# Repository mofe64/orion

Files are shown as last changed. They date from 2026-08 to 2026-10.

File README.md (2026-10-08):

# Orion

Orion is an expressive robotic lamp. Its Raspberry Pi runs the hardware runtime,
local speech recognition and synthesis, and the Codex agent coordinator. Studio
provides scene authoring, robot controls, and voice settings. Speech works with
Studio closed; Codex inference and web search still require the internet.

## Start here

1. [Quickstart](docs/quickstart.md): set up a Pi, connect Studio and deploy updates.
2. [System architecture](docs/system-architecture.md): the processes on the Pi and how they talk.
3. [How Orion moves](docs/motion-architecture.md): from a request to servo movement.
4. [Voice architecture](docs/voice-architecture.md): wake word, transcription, agent and reply.
5. [Hardware versions](docs/hardware-versions.md): V1 and V2 lamps, V2 calibration and centring.

Everything else is in the [documentation index](docs/README.md).

## How a conversation flows

```text
microphone ─▶ wake word ─▶ record command ─▶ transcribe ─▶ Codex agent
                (Rustpotter)  (Silero)         (Qwen)          │
speaker + movement ◀─ oriond ◀─ gateway ◀─ synthesize reply ◀──┘
                                             (Piper)
```

Everything above runs on the Pi. Only Codex inference and web search go to the
internet. `oriond` plays the reply, animates the lamp to match the speech, and
owns the servos and the RGBW light. Studio connects to the Pi's authenticated
gateway for authoring, controls and settings; closing Studio does not stop the
lamp.

## Repository map

| Path | Responsibility |
| --- | --- |
| `agent/` | Rust conversation runtime, memory/tools, and Codex integration |
| `orion-service/` | Pi voice/agent host and Studio remote client |
| `runtime/` | Rust `oriond` daemon, hardware and MuJoCo backends, lifecycle, scenes, lighting, and playback |
| `coordinator/` | Reusable Rust voice orchestration, Pi transport, buffering, and playback lifecycle |
| `speech/` | CPU Qwen and Piper workers plus optional Apple Silicon development adapters |
| `orion_studio/` | Tauri/React desktop application and Pi gateway |
| `motion/` | Pose and motion assets plus Python consumers of Rust-compiled trajectories |
| `scenes/` | Versioned multimodal scene documents |
| `description/` | Neutral Unified Robot Description Format (URDF) model and shared mesh assets |
| `simulation/mujoco/` | MuJoCo model, playback tools, and simulator checks |
| `hardware/` | Setup and operating instructions for servos, audio, and lighting |
| `voice/` | Pi microphone capture, Rustpotter, Silero endpointing, and coordinator transport |
| `audio/` | Named local audio cues |
| `docs/` | Cross-system architecture, configuration, animation references, and learning notes |

## Validation

Run these from the repository root unless a linked guide says otherwise:

```bash
cargo test --manifest-path orion-service/Cargo.toml
python3 -m unittest discover -s scripts/tests -v
cargo test --manifest-path coordinator/Cargo.toml
cargo test --manifest-path agent/Cargo.toml
cargo test --manifest-path runtime/Cargo.toml --all-targets
PYTHONPATH=motion .venv/bin/python -m pytest -q motion/test
python3 -m unittest discover -s orion_studio/tests -v

cd orion_studio
pnpm test
pnpm build
```

Some runtime integration tests expect the repository Python environment at
`.venv/bin/python`. Model-independent voice-worker tests use the worker's own
environment; see its [validation instructions](speech/README.md#validation).
Most Orion environments use Python 3.12; Pi speech uses Python 3.11 for its
CPU dependencies. Package metadata and setup scripts select the versions.
The root `.venv` supports workstation simulation. Keep separate environments for Pi
capture (`voice/.venv`), speech inference (`speech/.venv`), and
servo setup (`hardware/servo_setup/.venv`). Use `uv sync --locked` for
packages with a lockfile. The Pi gateway uses system Python. The release preparer creates separate
environments for capture and inference.

## Operating limits

Speech recognition and synthesis run locally on the Pi. Codex replies and web
search require internet access. Orion waits for reply playback to finish before
accepting a follow-up; acoustic echo cancellation and interruption during playback
are not implemented.

The gateway uses HTTP with a bearer token on a trusted local network. The agent
can search, manage explicitly requested memories and change the lamp through
validated tools. Movement remains under the runtime and explicit robot controls.
See [configuration](docs/configuration.md) for stored settings and credentials.

## Safety

Before powering or moving physical hardware, follow the
[servo setup guide](hardware/servo_setup/README.md). Software torque
disable is not an emergency stop. Keep an accessible physical power or torque
interruption available during hardware work.

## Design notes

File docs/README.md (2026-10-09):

# Orion documentation

## Start here

Read these in order when you are new to Orion:

1. [Quickstart](quickstart.md): set up a Pi, connect Studio and deploy updates.
2. [System architecture](system-architecture.md): the processes on the Pi and how they talk.
3. [How Orion moves](motion-architecture.md): from a request to servo movement.
4. [Voice architecture](voice-architecture.md): wake word, transcription, agent and reply.
5. [Hardware versions](hardware-versions.md): V1 and V2 differences, V2 calibration and centring.

## Reference

- [Motion reference](motion-reference.md): pose and motion schemas, styles, animation catalogue, trajectory compiler and servo control
- [Speech animation runtime](speech-animation-runtime.md): how reply audio becomes head and body gestures
- [Configuration](configuration.md): settings files, environment variables and deploy options
- [Runtime commands and lifecycle](../runtime/README.md)
- [Scene format](../scenes/README.md)
- [Motion asset folders](../motion/README.md)
- [Audio cues](../audio/README.md)
- [Robot description](../description/README.md)
- [Train and evaluate “Hey Orion”](wake-word-training.md)
- [Echo cancellation and barge-in design](echo-cancellation-and-barge-in.md) (software AEC proposals; V2 uses hardware AEC)

## Hardware setup

- [STS3215 servo setup, calibration and centring](../hardware/servo_setup/README.md)
- [V1 ReSpeaker HAT audio](../hardware/audio/README.md); V2 USB audio is in [hardware versions](hardware-versions.md#usb-capture-and-playback)
- [RGBW light](../hardware/lighting/README.md)
- [Wi-Fi fallback hotspot](networking.md)

## Component development

- [Studio](../orion_studio/README.md#development)
- [Runtime build and tests](../runtime/README.md#build-and-test)
- [Runtime in MuJoCo](../runtime/README.md#mujoco-daemon)
- [MuJoCo pose editor](../simulation/mujoco/README.md#calibrated-pose-editor)
- [Orion service](../orion-service/README.md)
- [Voice coordinator](../coordinator/README.md)
- [Agent runtime, memory and tools](../agent/README.md)
- [Pi speech workers and models](../speech/README.md#setup-on-the-pi)
- [Pi voice capture](../voice/README.md#setup)

## Experiment tooling

- [Servo tracking capture, trials and gain experiments](servo-tracking.md)

## Learning notes (V1 model)

- [Joint structure](learning_notes/orion_joints.md)
- [MuJoCo model](learning_notes/orion_mujoco_model_basics.md)
- [URDF basics](learning_notes/orion_urdf_basics.md)

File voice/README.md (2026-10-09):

# Orion voice listener

The Pi listener captures microphone audio, detects “Hey Orion” with Rustpotter,
confirms it with an openWakeWord phrase verifier, and uses Silero to find the
end of speech. It passes recordings to the onboard
coordinator and forwards voice-session events to `oriond` for acknowledgement,
waking and character feedback.

## Setup

Use [Pi installation and deployment](../docs/quickstart.md#prepare-a-new-pi)
to prepare the listener with the complete voice stack. The Pi needs working
[ReSpeaker audio](../hardware/audio/README.md), calibration and a Rust toolchain.
Deployment builds the native Rustpotter adapter and checks the active
reference model, retained trained model and packaged phrase verifier. See [wake-word training](../docs/wake-word-training.md)
for the evidence and rollback policy.

The listener runs as `orion-listener` with a Python 3.12 environment inside the
active release. Its WebSocket endpoint uses port 7448 and the Pi's
`~/.config/orion/studio-token`. The managed `--local-processor` setting reserves
processing ownership for a loopback connection. Separate authenticated controls
can inspect or change microphone mute.

## Capture and sessions

The listener opens synchronized stereo PCM16 capture at 16 kHz. It estimates
coarse direction from stereo frames and downmixes to mono for Rustpotter and ASR.
It keeps pre-roll and the current recording in memory. Mute, coordinator
cancellation and disconnect clear both buffers; acoustic rejection clears the
candidate recording and keeps the rolling pre-roll. Saving wake audio requires
the opt-in
[wake diagnostics](#troubleshooting).

A wake candidate opens a listener/coordinator session. The runtime session,
chime and brief light pulse wait for the acoustic verifier to accept it.
Acoustic rejection ends the candidate immediately and returns to listening,
preserving three seconds of pre-roll, Rustpotter state and verifier history.
The listener cancels runtime feedback for the rejected ID; the coordinator
clears that session and sends its cancellation control. Held audio is discarded
without ASR. A loaded verifier remains authoritative even when marked unhealthy;
that speed guard disables playback barge-in. If no verifier is loaded,
a short wake prefix reaches Qwen while full command capture continues.
Prefix verification and transcription of the complete utterance run in order. Follow-up
speech can remain buffered during confirmation. The coordinator rejects recordings
that reach the capture limit before submitting a command to the agent.

The listener reports when recording ends with `silence` or `max_duration`, including
capture time. These log entries contain no audio or transcript. See
[capture and session behavior](../docs/voice-architecture.md#capture-ownership-and-session-lifecycle)
for timing, limits and the Silero classifier.

Processing suppresses wake detections. On V2, playback keeps three seconds of
pre-roll and runs Rustpotter only while the acoustic phrase verifier is healthy.
A candidate leaves playback running until the verifier accepts it. Acceptance
stops the reply and starts a fresh verified wake session from that pre-roll;
rejection leaves the speaking session unchanged. A missing or unhealthy verifier
disables barge-in. V1 retains playback wake suppression.

Barge-in uses processed channel 0 and the XVF3800's hardware echo cancellation;
Orion does not add software AEC or raise the wake threshold during playback.
Only “Hey Orion” interrupts, and interruption sessions never request an attention
turn because Orion's voice can steer the board's beam. Alarm dismissal takes
precedence. After successful playback, the listener still establishes a quiet
baseline and opens the teal follow-up invitation.

## Settings and microphone startup

`--hardware v1` uses HAT capture routing. `--hardware v2` uses USB capture
without HAT mixer commands; `--capture-channels 2|6` and `--processed-channel N`
select the verified XVF3800 stream. The processed channel feeds the listener
without averaging raw microphone channels. V2 attention uses calibrated USB beam
observations when explicitly enabled; it defaults off. See [USB profile setup](../docs/hardware-versions.md#usb-capture-and-playback).

Microphone mute persists in `~/.config/orion/microphone.json`. The listener applies
capture routing before opening ALSA, discards startup frames, reapplies gain after
the ADC starts, and then reports readiness. Unmute can therefore take a short
startup interval before capture is ready.

Set microphone overrides in `~/.config/orion/voice.env` and restart the listener.
The [configuration reference](../docs/configuration.md#pi-runtime-and-listener)
lists wake sensitivity, gain, VAD and direction settings. Direction estimation
on V1 requires measured microphone spacing and channel orientation. V2 requires
the measured mounting offset and sign; both default to unset.

## Troubleshooting

On the Pi:

```bash
systemctl status orion-listener orion-voice-stack
journalctl -u orion-listener -u orion-voice-stack -n 60 --no-pager
```

To diagnose live acoustic-verifier rejection, set this in
`~/.config/orion/voice.env`, then restart the listener after deploying the change:

```bash
ORION_WAKE_DEBUG_DIR=/home/mofe/orion-wake-debug
```

The variable defaults unset: no diagnostic writer, audio files or additional
score buffer are created. When enabled, each accepted or rejected acoustic verdict
saves a `<UTC timestamp>-accepted/` or `-rejected/` folder containing `audio.wav` and
`meta.json`. The WAV holds up to four seconds of exact mono verifier input at
16 kHz, ending when the verdict is produced. Metadata records the session ID and
phase at the candidate, Rustpotter score, candidate/verdict sample positions,
all verifier chunk scores in that window (including ineligible warm-up scores),
verifier health, its last 250 processing times in seconds, and time since capture
last opened. `audio_start_sample` and `audio_end_sample` map WAV samples to the
verifier's sample positions; capture reopening resets that origin. Alarm
dismissal does not save a recording.

A bounded queue writes on a separate thread and keeps the newest 50 diagnostic
folders. A full queue drops snapshots and logs a warning; disk errors also log
without changing wake decisions. Once a minute during capture,
`voice.capture_read_timing` reports `reads_over_40_ms`. Read latency includes
dispatch to and from the capture worker thread, so CPU scheduling delays count.

The audio stays on the Pi; it is not uploaded or included in Studio history.
Unset the variable and restart the listener after testing, then delete the saved
audio and metadata after use. For the V2 check, make five wakes from idle and
three from the follow-up window, then replay each WAV through `StreamingScorer`
on the Pi. High offline scores paired with low live scores point toward verifier
state or timing. Low scores in both point toward the live audio: compare it by
ear and spectrum with the measurement recordings. These diagnostics do not change
wake thresholds, models or verification rules.

For dependency repair, prepare and deploy a complete replacement release through
the [Pi deployment procedure](../docs/quickstart.md#deploy-to-the-pi). It builds the
Python environment before switching service paths. Playback routing and speaker
checks are described in [audio setup](../hardware/audio/README.md).

If wake detection succeeds but the body stays at rest, inspect
`voice.wake_verifier` acceptance and the runtime's rest status. With
`--no-verifier`, inspect Qwen confirmation: the candidate chime can play even
when Qwen rejects the phrase. Home movement requires confirmation and a healthy
rest lifecycle. If a recording
ends early, inspect the VAD configuration, capture gain and endpoint reason before
changing the ASR model.

## Intermediate tool speech

The listener advertises `toolFeedback: true`. After search acknowledgement plays,
`session.processing` restores thinking feedback in the same session. Wake
detection stays suppressed during processing. V2 playback accepts verified
barge-in, and alarm dismissal takes precedence. During synthesis and playback,
`session.keepalive` renews the
180-second lease and forwards `voice SESSION keepalive` to the runtime without
changing the phase or triggering feedback. Unknown and expired sessions cannot
renew. `session.processing` and `session.playing` mark actual phase transitions. A long response can continue while the
coordinator owns it; a disappeared owner still expires. Final `session.finish`
starts the echo guard and follow-up invitation. See [agent conversation](../docs/voice-architecture.md#agent-conversation-and-memory).

## Alarm dismissal

The listener polls `routines status` over the runtime socket every 200 ms. A ringing
alert interrupts an existing voice session and enables Rustpotter detection during
playback. “Hey Orion” sends a local stop request and consumes that wake phrase.
It works without a connected coordinator and does not send alarm audio to ASR.
Microphone mute still closes capture. The runtime enforces the five-minute sound
limit independently.

## Measure the XVF3800 on V2

`orion_voice.xvf_measure` records every USB capture channel while it polls the
board's beam azimuths, per-beam speech energy and AEC convergence over the USB
control interface (vendor `2886`, product `001a`). With `--play` it plays a WAV
through the same card, so the board's echo canceller receives it as the far end,
exactly as `oriond` playback does. It only reads board parameters; it never
changes them.

One-time access to the control interface for the service user (log out and in
again if `plugdev` was just added):

```bash
echo 'SUBSYSTEM=="usb", ATTR{idVendor}=="2886", ATTR{idProduct}=="001a", MODE="0660", GROUP="plugdev"' \
  | sudo tee /etc/udev/rules.d/60-orion-xvf3800.rules
sudo udevadm control --reload && sudo udevadm trigger
groups | grep -w plugdev
```

The listener holds the capture device, so stop it for the session and start it
again afterwards:

```bash
sudo systemctl stop orion-listener
# ... trials ...
sudo systemctl start orion-listener
```

Make a reply WAV in Orion's voice. Include “Orion” so self-triggers show up:

```bash
ORION_PIPER_MODEL_DIR=$HOME/.local/share/orion/voice-stack/models/piper-alba-medium \
PYTHONPATH=speech speech/.venv/bin/python - <<'PY'
import wave
from orion_speech_worker.piper import PiperAlbaSynthesizer
text = ("Orion here. The kettle takes about three minutes, so you have time to find a mug. "
        "If you want, Orion can set a timer while you wait, and remind you when it is done.")
pcm = b"".join(chunk.pcm for chunk in PiperAlbaSynthesizer("piper-alba-medium").stream(text))
with wave.open("/tmp/orion-reply.wav", "wb") as out:
    out.setnchannels(1); out.setsampwidth(2); out.setframerate(24000); out.writeframes(pcm)
PY
```

The tool needs `pyusb`, which the voice environment gains on the next deploy.
Run trials from the `voice` folder. Trials land in `~/orion-measurements/`:

```bash
cd voice
M=".venv/bin/python -m orion_voice.xvf_measure"
$M record --label echo-quiet --play /tmp/orion-reply.wav          # nobody speaks
$M record --label echo-moving --play /tmp/orion-reply.wav                       # run a motion from Studio meanwhile
$M record --label barge-1m --play /tmp/orion-reply.wav --expected-azimuth 0     # say “Hey Orion” twice over the reply from 1 m
$M record --label barge-2m-moving --play /tmp/orion-reply.wav --expected-azimuth 0
$M record --label dir-090 --seconds 8 --expected-azimuth 90                     # say “Hey Orion” three times from that position
```

`--expected-azimuth` is the speaker's position in degrees, counter-clockwise from
the lamp's front seen from above. Repeat the direction trial every 45° (0, 45, …,
315) at about 1.5 m. Then summarise everything:

```bash
$M analyze ~/orion-measurements/* --json ~/orion-measurements/summary.json
```

The summary reports, per trial, the level of channel 0 (conference) and channel
1 (ASR) before, during and after playback, how quickly `AEC_AECCONVERGED` reached
1, Rustpotter hits per channel (marked when they fall inside playback) at the
[managed Rustpotter threshold](../docs/configuration.md#pi-runtime-and-listener),
and the auto-select beam's azimuth while the board reports speech. Across
direction trials it fits the board's mounting offset and
rotation sense, and prints the worst error after that fit. With the six-channel
firmware it also reports echo reduction against the raw microphones.

## Check V2 barge-in on the lamp

From 1–2 m, interrupt ten long replies with “Hey Orion” and a new command: at
least nine must stop and capture the command. Play fifty uninterrupted replies,
including replies saying “Orion”: none may interrupt themselves. After an
interruption, ask “what were you saying?” to check retained conversation context.
The [coordinator lifecycle](../docs/voice-architecture.md#wake-phrase-barge-in)
explains why the new command can wait for the old agent turn to finish.

## Calibrate V2 attention

Keep processed channel 0. Fit the mounting with the base cover in its normal
position: from about 1.5 m, record `dir-front`, `dir-left` and `dir-right` trials
with `--expected-azimuth 0`, `90` and `270`, saying “Hey Orion” three times at
each position. Run `analyze` as above and copy its mounting `sign` and
`offset_deg` into the [XVF listener settings](../docs/configuration.md#pi-runtime-and-listener).
Set `ORION_XVF_DIRECTION=1` only after the positions separate clearly. If the
cover collapses the positions into two beams, report that acoustic obstruction
before enabling facing.

The poller reads auto-select beam 3 at 20 Hz without blocking capture. It converts
board radians to lamp degrees with `wrap180(sign * (board_deg - offset_deg))`:
positive is counter-clockwise from front seen from above, toward the lamp's left.
The default front sector is ±30 degrees; other angles vote for their nearer side,
including angles behind the lamp. A turn needs at least five speech-energy votes
in three seconds with 75% agreement. Centre/unknown send no attention command.

Before acceptance, verify that `attention_left` physically points left; V2
attention poses still require hardware playback validation. Report swapped poses
to the deploy smoke-test owner. Try five wakes from each side and front: at least
12 of 15 must face correctly or remain front, with no wrong-way turns. Board
access/read failures log once and leave voice working without a turn.

## Validation

With a prepared listener environment, run from the repository root:

```bash
PYTHONPATH=voice voice/.venv/bin/python -m unittest discover -s voice/tests -v
```

Tests cover endpointing, retained command audio, mute, disconnects, session
ordering and transport failures. Physical checks establish capture quality,
speaker pickup and direction behavior on the assembled robot.

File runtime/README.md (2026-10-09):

# Orion Rust runtime

`oriond` owns Orion's movement, RGBW light and speaker playback. It loads poses
and motions, compiles smooth joint trajectories, applies calibration, checks
measured completion and coordinates character behavior, scenes and speech
animation. The hardware and MuJoCo backends use the same 50 Hz runtime loop.

See the [system architecture](../docs/system-architecture.md) for
workstation/Pi boundaries and device ownership.
Select `--hardware v1` or `--hardware v2` for the lamp interfaces and asset paths.
The [hardware-version guide](../docs/hardware-versions.md) defines the v2 joint
mapping, maintenance defaults and calibration paths.

For movement internals, use:

- [How Orion moves](../docs/motion-architecture.md)
- [Motion reference](../docs/motion-reference.md)

The physical transport uses
[`rustypot`](https://github.com/pollen-robotics/rustypot) for the STS3215
serial packet format, synchronized reads/writes, and communication. This
servo-wire protocol is unrelated to Orion's asset format. Orion retains its
own raw register map and conversions for firmware bytes at addresses 0/1, a
one-byte maximum-acceleration register at address 85, and project-specific
encoder/velocity conversions.

## Build and test

Use a toolchain that supports the crate's Rust 2024 syntax. Run from the repository root:

```bash
cargo build --manifest-path runtime/Cargo.toml
cargo test --manifest-path runtime/Cargo.toml --all-targets --locked
cargo fmt --manifest-path runtime/Cargo.toml --check
cargo test --manifest-path runtime/Cargo.toml --doc --locked
python3 -m unittest discover -s runtime/tests -p 'test_*.py' -v
```

Component tests live beside their Rust implementations. Rest policy tests use
explicit clock values and injected driver failures; app tests check command
validation and session ownership without reproducing the server loop.

Integration tests live in `tests/` and send commands to the built `oriond` through
private temporary Unix sockets. `test_daemon.py` covers startup, maintenance,
command handling, and movement/scene completion. `test_rest.py` covers automatic
rest, confirmation during descent, attention freshness, speech ordering, and
fault handling through the real server loop. Both share process and socket
helpers in `daemon_support.py` and use recording audio and lighting.

The deterministic following driver verifies software coordination, including
injected stalled movement and torque-release failure. It does not model physics.
Native MuJoCo tests use the tracked model and expect the
[simulator Python environment](../simulation/mujoco/README.md#python-environment)
at `.venv/bin/python`. Physical rest/wake acceptance remains separate;
see the [rest/wake integration tests](tests/test_rest.py).
Set `ORION_TEST_BIN_DIR` to an absolute binary directory to test a release build.

## Opt-in servo tracking

Pass `--tracking-log FILE` with `--serve` to capture exact trajectory goals and
measured feedback without blocking on file I/O. The file must not exist.
See [servo tracking capture](../docs/servo-tracking.md) for timing semantics,
repeatable idle/speech trials, analysis commands and measurement limitations.

## Experimental servo gains

Hardware measurements can select one arm's P/I coefficients with
`--experimental-servo-gains shoulder_pitch_joint:24:0` or
`--experimental-servo-gains elbow_pitch_joint:40:0`. This flag requires
`--serve --backend hardware --tracking-log FILE`. It accepts P from 1 to 254
and I from 0 to 1, rejects repeated selections and other joints, and preserves D.
Without the flag, the commissioned profiles are unchanged.

The coefficients are EEPROM settings, not process-local servo state. The driver
writes only differences, but ending the daemon does not itself restore them.
Use a temporary service, re-apply the original profile while torque is off, and
read back P/D/I and the EEPROM lock before returning to ordinary operation.
See [gain experiment procedure](../docs/servo-tracking.md#gain-experiments).

## Deploy an update to the Raspberry Pi

Use the [Pi deployment procedure](../docs/quickstart.md#deploy-to-the-pi) from the
workstation after committing and pushing the intended code. It prepares all four
services in a separate release, updates built-in YAML after confirmed mechanical
rest, and runs a physical smoke test before returning to rest with lights and
torque off. The [configuration reference](../docs/configuration.md#raspberry-pi-deployment)
explains saved settings, overrides and the existing asset catalog.

For logs, readiness checks and rollback, follow
[recovery](../docs/quickstart.md#logs-and-recovery). Normal character startup can
move Orion home. The default inactivity interval is documented under
[automatic rest](../docs/system-architecture.md#automatic-rest-and-waking).

## MuJoCo daemon

Run the daemon without opening a serial port:

```bash
runtime/target/debug/oriond --serve --backend mujoco \
  --start-pose attentive --character-on-start off
```

In another terminal, use the normal client commands:

```bash
runtime/target/debug/oriond --status
runtime/target/debug/oriond --configure
runtime/target/debug/oriond --enable
runtime/target/debug/oriond --goto home --duration 3.0 --wait
runtime/target/debug/oriond --play look_at_left_expressive --wait
runtime/target/debug/oriond --stop
runtime/target/debug/oriond --disable
```

Use `--socket`, `--scene`, `--python`, or `--start-pose` to override the
defaults. The MuJoCo bridge reports measured positions and velocities and
accumulates the shared base translation, tilt, height, and contact policy in
`motion/config/stability_limits.yaml`.

## Physical hardware

The Rust transport has been validated on Orion's Raspberry Pi and five-servo
STS3215 bus. Managed deployment selects binaries from a release directory while
keeping the existing catalog root for poses, motions, scenes and cues. Inspect
`systemctl cat oriond` to find the installed executable and arguments.

Servo configuration writes are checked by reading the register back. If a write
acknowledgement times out, configuration continues only when that read confirms
the exact requested value; it does not resend the write. A mismatched value or
failed read-back aborts configuration before torque is enabled. Errors identify
the servo and register. This recovery applies to profile settings, while torque
and EEPROM lock commands still require their acknowledgements.

The examples below use a runtime built in the development checkout. Stop the
installed `oriond.service` before opening its serial, RGBW or audio devices with
a direct diagnostic process. For a manual configure/enable sequence, start with
`--character-on-start off` so automatic startup does not move the robot first.

### Read hardware state without enabling torque

```bash
cd /home/mofe/dev/orion

runtime/target/release/oriond --check \
  --port /dev/ttyACM0 \
  --calibration /home/mofe/.config/orion/servo_calibration.json
```

`--check` reads one direct state snapshot and exits. It does not enable torque
or write servo registers.

### Start the runtime

In Terminal 1:

```bash
cd /home/mofe/dev/orion

runtime/target/release/oriond --serve \
  --backend hardware \
  --port /dev/ttyACM0 \
  --baud-rate 1000000 \
  --character-on-start off \
  --calibration /home/mofe/.config/orion/servo_calibration.json
```

The expected startup message is:

```text
oriond: observing hardware at 50 Hz on /tmp/oriond.sock
```

Leave Terminal 1 running. The foreground daemon owns the serial connection and
serves commands through `/tmp/oriond.sock`.

### Control Orion

Open Terminal 2:

```bash
cd /home/mofe/dev/orion

runtime/target/release/oriond --status
runtime/target/release/oriond --configure
runtime/target/release/oriond --enable
runtime/target/release/oriond --status
```

Run a named pose:

```bash
runtime/target/release/oriond --goto home --duration 3.0 --wait
```

Run an authored movement:

```bash
runtime/target/release/oriond --play look_at_left_expressive --wait
```

Movement submission is asynchronous unless `--wait` is present. Every accepted
`goto` or `play` receives a daemon-local `run_id` and follows this functional
lifecycle:

```text
executing -> settling -> completed
                      \-> timed_out
executing/settling ----> cancelled
```

`executing` means authored trajectory frames are still being sent. `settling`
begins after the final target is sent and compares measured joint position and
velocity against the completion tolerances. The measured state must remain
within tolerance for the full settle duration. The defaults are
`0.05 rad`, `0.05 rad/s`, `0.25 s` settled, and a `2.0 s` settling timeout.

Status JSON keeps only the active `motion` and the most recent terminal
`last_motion`. Clients retain the returned `run_id` and follow that ID through
these fields. IDs reset when the daemon restarts.

`--wait` is a thin client over the same status contract. It exits `0` for
`completed`, `4` for `timed_out`, and `5` for `cancelled`. Daemon command
rejection exits `3`, invalid CLI usage exits `2`, and transport/runtime errors
exit `1`.

Stop the active movement and hold its commanded position:

```bash
runtime/target/release/oriond --stop
```

### Normal shutdown

Move Orion to its captured mechanical rest pose before disabling torque:

```bash
runtime/target/release/oriond --goto rest --duration 3.0 --wait
```

Once the rest run reports `completed`, disable torque:

```bash
runtime/target/release/oriond --disable
```

Then stop Terminal 1 with `Ctrl+C`.

The normal hardware lifecycle is `--serve`, `--configure`, `--enable`, motion
commands, `--goto rest --wait`, confirmed completion, and finally `--disable`.
Neither `--disable` nor stopping the daemon is a physical emergency stop; an
accessible hardware torque/power interruption remains required during physical
trials.

## Runtime structure

| Location | Responsibility |
| --- | --- |
| `src/main.rs` and `src/lib.rs` | Thin executable entry point and public library exports. |
| `src/app/options.rs` | CLI arguments, defaults, help, and validation. |
| `src/app/client.rs` | Command submission, movement/scene waiting, and exit codes. |
| `src/app/server.rs` | Startup, device wiring, signal handling, and the 50 Hz loop. |
| `src/app/commands.rs` | Voice, lamp, character, speech, scene, movement, and reload dispatch. |
| `src/control/` | Runtime core, movement ownership, measured completion, and status. |
| `src/motion/` | Pose loading, motion library, trajectory compilation, styles, and calibration. |
| `src/devices/driver.rs` | Shared `RuntimeDriver` and `JointLimit` contracts. |
| `src/devices/sts3215/` | Physical servo driver, profiles, registers, and transport. |
| `src/devices/mujoco.rs` and `mujoco_bridge.py` | Simulator driver and its Python worker. |
| `src/devices/audio.rs` and `src/devices/lighting.rs` | Local sound and RGBW device implementations. |
| `src/expression/` | Character behavior, scenes, speech, voice feedback, and lamp programs. |
| `src/expression/rest.rs` | Inactivity deadline, rest/wake completion, voice readiness, and light gating. |
| `src/ipc/socket.rs` | Private Unix command transport. |
| `src/bin/orion-trajectory.rs` | Shared trajectory export executable. |

`CharacterCoordinator::preempt_idle_or_thinking()` interrupts either tracked
background movement. Generic movement code uses the shared device interface,
while the STS3215 and MuJoCo implementations provide their own I/O.
See [the speech animation runtime](../docs/speech-animation-runtime.md) for planning and execution.

## Lighting, audio, and local scenes

The physical light adapter selects the v1 40-pixel matrix or v2 24-pixel ring on
Pi 5 BCM12. After installing and reboot-verifying the persistent RP1
pulse-width modulation (PWM) setup described in `hardware/lighting/README.md`,
direct output is available without starting the servo daemon:

```bash
runtime/target/release/oriond --light 8 3 0 20
runtime/target/release/oriond --light-pixel 0 0 0 0 8
runtime/target/release/oriond --lights-off
```

Arguments are logical `RED GREEN BLUE WHITE` bytes from 0 through 255. The
adapter performs the physical green-red-blue-white (GRBW) ordering and 800 kHz
symbol encoding. This
path has been tested on the physical robot, including all four channels,
the full matrix, and all-off output.

The v1 physical audio adapter uses the stable Advanced Linux Sound Architecture
(ALSA) pulse-code modulation (PCM) device
`plughw:CARD=seeed2micvoicec,DEV=0`. It applies the confirmed ReSpeaker V2 JST
mixer route whenever the hardware daemon starts. Named, local, stereo WAV
cues live under `audio/cues/` and can be checked without starting the
servo daemon:

```bash
runtime/target/release/oriond --play-cue acknowledge_warm
```

V2 selects `plughw:CARD=Array,DEV=0`, skips the HAT mixer route and sets the
XVF3800 playback controls to 0 dB instead. Add `--hardware v2` to direct light
or cue commands for that lamp.

The direct command blocks until `aplay` exits and returns nonzero if playback
fails. Do not run it concurrently with a hardware daemon that may also own the
ALSA PCM.

Direct warm-cue playback and the complete `acknowledge_left` and
`acknowledge_right` motion/light/audio scenes use the same audio
path as the character coordinator.

Portable scenes live under `scenes/v1/` or `scenes/v2/`, selected by `--hardware`.
The `format_version: 2` schema coordinates
non-overlapping motion clips with parallel spatial
RGBW effects and queued audio. Events use seconds or Rust-compiled motion
markers from one supplied monotonic clock. Scene files are validated against
the pose, motion, effect, and cue libraries before playback.

The scene player implements `SceneMotionDevice` for `RuntimeCore`, so it starts
motion through the existing `goto`/`play` command boundary and follows the
returned movement `run_id`. A scene remains active while movement is executing
or settling, while an audio cue is playing, or while a light transition is in
progress. It propagates movement timeout, cancellation, and failed WAV player
exit status.

Hardware `--serve` opens `/dev/ws281x_pwm`, clears it to establish a known
initial state, configures the selected hardware's mixer, and owns both devices until the
process exits. Direct lighting and cue commands therefore should
not run concurrently with the daemon. MuJoCo uses recording lighting and audio
backends with the identical scene clock and lifecycle.

With the daemon running, test light and audio without enabling torque:

```bash
runtime/target/release/oriond --run-scene deployment_smoke --wait
runtime/target/release/oriond --scene-status
```

After `--configure` and `--enable`, run the coordinated motion, light, and
audio scene:

```bash
runtime/target/release/oriond --run-scene acknowledge_left --wait
```

Every accepted scene receives a daemon-local `run_id`. `--scene-status` keeps
only the active `scene` and most recent terminal `last_scene`; IDs and results
reset when the daemon restarts. Scene states are `executing`,
`completed`, `timed_out`, `cancelled`, and `failed`. `--stop-scene` cancels the
scene and its active movement. `--wait` exits `0`, `4`, `5`, or `6` for
completed, timed out, cancelled, or failed respectively.

The selected scene library is recursive, including its `user/` subdirectory.
User-authored poses load from `motion/user/poses/<version>/`, and user motions
live under `motion/motions/<version>/user/`, where `version` is `v1` or `v2`.
Built-in names cannot be shadowed. At startup and
reload, `oriond` validates every pose against the active driver limits and
validates every motion keyframe reference and timing value.

The private Unix protocol supports `joint limits` so the authenticated Studio
gateway can report the running driver's calibrated ranges without exposing
servo registers. It also supports `asset reload`, which reloads poses,
motions, and scenes together and atomically replaces the validated runtime
libraries while no movement or scene is active. `scene reload` remains the
narrower scene-only operation.

The private `scene preview DOCUMENT` command is reserved for the authenticated
Studio gateway. It parses one inline v2 scene against the loaded pose, motion,
and audio libraries, then starts the normal scene
coordinator without adding it to the library or filesystem. The gateway limits
the compact document to 3,000 UTF-8 bytes so the complete command stays within
the Unix protocol's fixed 4,096-byte input boundary. Preview still uses normal
scene run IDs, status, cancellation, movement validation, and lifecycle rules.

Reload re-reads the daemon's configured scene directory, validates all pose,
motion, and audio-cue references, and atomically replaces the in-memory catalog
only when no scene is active. No command accepts an arbitrary asset path;
inline preview is the sole non-persisted scene-body operation and the raw
socket remains local to the Pi.

Unix requests are UTF-8 lines terminated by a newline (or a client write-side
EOF). The server retains partial reads and writes without blocking the motor
loop, bounds pending clients to 32, and retires incomplete connections after
one second. Oversized commands are rejected before dispatch.

For manual development, build and run `oriond` directly from this source tree
only after stopping the installed service. Normal Pi operation uses the executable
selected by `oriond.service`.

## Speech playback

The Pi's Piper Alba worker generates response audio. The onboard
coordinator buffers and uploads mono PCM16 24 kHz WAV through the local
authenticated gateway. `oriond` accepts a validated spool identifier through its private
`speech file` operation and owns speaker playback. Streaming uses `speech stream`,
ordered `speech append` commands and an explicit `speech end`, all under one run
ID and one player process. Stream and append commands accept an optional final
`cues=agree,disagree` token (at most four canonical names). For scoped voice
streams it follows the session ID; it never bypasses session ownership checks.
Each cue uses its chunk's first audio frame. One-shot `speech file` playback
has no reaction cues. See [streaming replies](../docs/voice-architecture.md#streaming-replies-and-timing)
for buffering, limits and timing semantics.

Inspect or cancel playback with:

```bash
runtime/target/release/oriond --speech-status
runtime/target/release/oriond --stop-speech
```

Speech states are `queued`, `playing`, `completed`, `failed`, and `cancelled`.
Only the active run and most recent terminal result are retained. The spool
WAV is removed after completion, cancellation, or playback failure. Stream chunks
remain bounded to two seconds. The stream accepts thirty minutes of audio and
rejects more with an explicit sanity-limit reason. PCM is released after the
player accepts it; energy frames are computed incrementally, including partial
frames across chunk boundaries. Compact, absolute-indexed animation analysis is
retained until completion. Complete-WAV uploads retain their 120-second bound.
`voice SESSION keepalive` renews an active processing, thinking or speaking lease
without changing phase, history or feedback; stale and expired IDs are rejected.

`SpeechCoordinator` validates and analyzes the waveform, while
`CharacterCoordinator` composes one anchor-relative utterance performance and
the daemon drives the `speaking_energy` light. See
[Speech performance policy](../docs/motion-reference.md#speech-performance-policy)
for the animation policy.

The Pi listener captures stereo audio (ReSpeaker HAT on V1, XVF3800 on V2) and runs Rustpotter, then
uses Silero to find speech boundaries and sends complete mono utterances to the
onboard coordinator for Qwen confirmation and transcription. See [Pi voice setup](../voice/README.md).

## Character startup and voice attention

Serving starts character mode by default: configure servos, enable holding torque,
move home, then enter idle after measured completion. Use
`--serve --character-on-start off` for an observation-only maintenance startup.
Studio Stop lasts until an explicit character start or the next daemon startup
with character mode enabled. A timed-out or cancelled home
movement leaves character off; the terminal movement remains visible in status.

The Pi listener sends `voice SESSION verify` before the short wake prefix ASR
pass; recording continues while verification runs. It sends
`voice SESSION confirmed` after ASR accepts the wake and
waits for its acknowledgement. If direction is known with confidence at least
0.75, it may then send `voice SESSION attend_left AGE_MS` or `attend_right AGE_MS`.
The rest coordinator waits for home and checks that the observation is still
younger than three seconds before requesting attention.

The lower-level `character attend left CONFIDENCE` and `character attend right
CONFIDENCE` commands remain available for explicit attention requests. They
require confidence in [0.75, 1], a powered available character, and a bounded yaw
transition. The character holds the completed attention anchor, then returns to
the prior anchor 15 seconds after neutral inactivity. Explicit foreground work
discards that pending return. See the
[animation catalogue](../docs/motion-reference.md#animation-catalogue).

## Agent lighting commands

The authenticated gateway translates `lamp_effect` operations into the private
`lamp-effect JSON` daemon command. JSON fields are optional `brightness` (0–1),
`effect` (`solid` or a supported lighting effect), and `colors` (one or two
arrays of four integer RGBW channels, 0–255). An update must supply at least one
non-null field. Invalid patches leave the existing program unchanged.

Brightness-only updates preserve the palette and effect; zero brightness is
fully off. Lamp programs resume after higher-priority voice feedback or speech.
Scene or speech playback rejects changes until it finishes. The existing
`lamp R G B W` command still sets a steady color. `lamp-status` reads the manual
program as `lamp` with brightness in percent, effect and RGBW colors, or null when
no manual program exists. The gateway exposes this through `lamp_status` and the
agent through `get_lighting`. Starting the character clears the manual program.

## Mode and alert commands

The private Unix socket accepts these commands. The gateway exposes them through
its authenticated `routines` operation; Studio and agent tools use that route.

```text
routines status
routines {"action":"set_mode","mode":"lamp"}
routines {"action":"set_mode","mode":"idle"}
routines {"action":"set_sound","kind":"alarm","sound":"club_alarm"}
routines {"action":"set_sound","kind":"timer","sound":"funny_alarm"}
routines {"action":"timer","seconds":300,"label":"Tea"}
routines {"action":"alarm","due_unix":1893571200,"label":"Morning"}
routines {"action":"list"}
routines {"action":"cancel","id":1}
routines {"action":"stop"}
sleep CURRENT_CONFIRMED_VOICE_SESSION_ID
```

Alarm timestamps are Unix seconds and must be in the future. `sleep` waits for
the owning voice session and its speech to finish. `character rest` remains the
immediate controlled rest command. The `character status` response includes
`rest.mode`, `rest.sleep_requested` and `routines`; alert status includes pending
and recent entries, remaining ringing time and playback errors. `sounds` contains
the saved `alarm` and `timer` defaults; `available_sounds` supplies IDs and display
names, and `ring_sound` identifies the active sound. Supported IDs are `two_tone`
(the default), `club_alarm` and `funny_alarm`. `set_sound` changes only the named
preference and takes effect when a later alert group starts. See
[timer and alarm behavior](../docs/system-architecture.md#timers-and-alarms) and
[saved state](../docs/configuration.md#saved-files).

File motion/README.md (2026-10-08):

# Orion motion assets

Orion loads built-in and user-authored pose and motion files from this
directory. The Rust runtime parses those assets and compiles their trajectories.

## Ownership

- `config/v1/poses.yaml` and `config/v2/poses.yaml` contain each hardware version's built-in complete five-joint poses.
- `user/poses/v1/` and `user/poses/v2/` contain Studio-authored poses.
- `motions/v1/` and `motions/v2/` contain each version's absolute actions and anchor-relative character clips.
- `motions/v1/user/` and `motions/v2/user/` contain Studio-authored motions.
- `config/stability_limits.yaml` contains MuJoCo reporting policy; it is not a
  physical command limit.

The active Pi calibration is the hardware position authority. The tracked
`simulation/mujoco/config/servo_calibration.json` is its offline validation
counterpart. Rust is the only trajectory compiler; Python code validates and
consumes the exported 50 Hz sample document.

Pi deployment updates built-in pose and motion YAML from the selected Git commit,
including replacing local edits to built-ins. It preserves user-authored assets
and calibration and backs up replaced or retired built-ins for rollback. See
[Pi deployment](../docs/quickstart.md#deploy-to-the-pi) for the physical smoke test
and release-switch sequence.

## Documentation

- [How Orion moves](../docs/motion-architecture.md): how a request becomes servo movement.
- [Motion reference](../docs/motion-reference.md): schemas, styles, catalogue,
  trajectory compiler and servo control, including how to export a trajectory.

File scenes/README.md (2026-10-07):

# Orion scene v2

Scenes coordinate named motion, RGBW effects, and local audio under one
monotonic clock. Built-in and Studio-authored scenes use `format_version: 2`.
The runtime resolves named actions into calibrated hardware commands.

```yaml
format_version: 2
scene:
  name: acknowledge_left
  description: One fluid left turn with warm acknowledgement.
  motion:
    - {at: 0.0, play: look_at_left_expressive}
  lighting:
    - {at: 0.0, effect: attentive_focus, intensity: 0.65, duration: 1.6, transition: 0.2}
    - {on_marker: notice, effect: acknowledge_pulse, intensity: 0.8, duration: 0.65}
  audio:
    - {on_marker: notice, cue: acknowledge_warm}
  finish: {anchor: final_pose, lighting: pose_default}
```

The motion track is ordered and may not overlap. Lighting and audio may use an
absolute `at` time or a named motion `on_marker` trigger. Marker timing comes
from the retimed Rust trajectory, so expression remains synchronized when the
STS3215 speed ceiling stretches motion. One audio cue owns playback at a time;
due cues queue in authored order.

Completion waits for the final motion's measured settle, the last light effect
or transition, and audio playback. The final measured position becomes the
next character anchor, and the scene restores the nearest pose's
`default_lighting`. Cancellation stops scene-owned movement and audio.

The v2 effect vocabulary is `warm_idle_breathe`, `attentive_focus`,
`thinking_drift`, `speaking_energy`, `acknowledge_pulse`, `curious_sweep`,
`delight_spark`, `settle_glow`, and `off`. Every frame contains 40 RGBW
pixels for V1's 8×5 matrix or 24 for V2's ring, selected by the hardware profile. Cue names resolve to WAV stems under
`audio/cues/`.

Built-ins live in `scenes/v1/` and `scenes/v2/`; user scenes live in the
selected version's `user/` subdirectory.
Studio publishes through the authenticated v2 gateway. The gateway writes
transactionally, asks `oriond` to validate and reload the complete catalog,
and rolls back a rejected update. Built-ins cannot be shadowed.

Run a scene through the owning daemon:

```bash
runtime/target/release/oriond --run-scene acknowledge_left --wait
runtime/target/release/oriond --scene-status
```

`deployment_smoke` is a lighting and audio diagnostic that can be requested
explicitly. The release deployment does not run expression scenes automatically.
Mechanical rest uses the runtime rest coordinator, which tracks descent to the
calibrated pose and releases torque after measured completion.

## Studio-authored light effects and scoped assets

Lighting events also accept `constant`, `pulse`, `breathe`, and `fade`. `colors`
contains one stage for constant or two for the other effects. Each stage is
`warm_white` (the dedicated white channel) or a `#rrggbb` color. Optional `levels`
sets per-stage brightness in the range 0–1; `intensity` scales the whole effect.
`period` is the pulse/breathe cycle length in seconds, at least 0.1. Fade spans
`duration`. Pulse and breathe default to 15% base brightness and 100% peak brightness.

An optional top-level `studio` object preserves scene-owned pose and movement data.
The Studio gateway validates ownership names, stages those dependencies, and reloads
the asset libraries when publishing. The runtime ignores the metadata itself; moving
a bundled scene file directly to the Pi does not install its dependencies. See the
[Studio editor documentation](../orion_studio/README.md#animation-library-and-scene-editor).

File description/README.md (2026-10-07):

# Orion robot description

Orion's simulator-independent robot-description assets include:

- `urdf/orion.urdf` is v1's neutral kinematic, visual, collision, and inertial
  description. Mesh references are relative and require no ROS package index.
- `meshes/` is the single shared geometry source used by both the URDF and
  MuJoCo.
- `urdf/orion-v2.urdf` matches V2.1 joint transforms, visual meshes and estimated
  inertias. It references portable meshes under `simulation/mujoco/v2/meshes/`.
  Its effort/velocity limits are zero placeholders and it has no collision
  elements; it is not a commissioned controller or contact model. See
  [V2 simulation and mass estimates](../docs/hardware-versions.md#cad-urdf-and-mujoco).

Simulator control plugins and launch configuration belong in their backend,
not in the neutral URDF. Orion's executable calibrated zero and joint ranges
for v1 remain encoded in `simulation/mujoco/robot.xml` and checked against the tracked
servo calibration.

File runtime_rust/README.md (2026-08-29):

# Orion Rust runtime

`runtime_rust` is Orion's ROS-independent native runtime. It implements the
`oriond` command protocol, lifecycle, pose and motion loading, quintic
interpolation, calibration contract, STS3215 profile, and 50 Hz state
snapshots.

The physical transport uses
[`rustypot`](https://github.com/pollen-robotics/rustypot) for protocol-v1 packet
parsing, synchronized reads/writes, and serial communication. Orion retains its
own raw register map and conversions for firmware bytes at addresses 0/1, a
one-byte maximum-acceleration register at address 85, and project-specific
encoder/velocity conversions.

## Build and test

Install a current Rust toolchain, then run from the repository root:

```bash
cargo build --manifest-path runtime_rust/Cargo.toml
cargo test --manifest-path runtime_rust/Cargo.toml --all-targets
```

The tests cover the complete runtime contract and launch Orion's native MuJoCo
model through the same Rust daemon state machine used by hardware.
MuJoCo tests expect the repository Python environment at `.venv/bin/python`.

## MuJoCo-first daemon

Run the daemon without opening a serial port:

```bash
runtime_rust/target/debug/oriond --serve --backend mujoco \
  --start-pose attentive
```

In another terminal, use the normal client commands:

```bash
runtime_rust/target/debug/oriond --status
runtime_rust/target/debug/oriond --configure
runtime_rust/target/debug/oriond --enable
runtime_rust/target/debug/oriond --goto home --duration 3.0
runtime_rust/target/debug/oriond --play look_at_left_expressive
runtime_rust/target/debug/oriond --stop
runtime_rust/target/debug/oriond --disable
```

Use `--socket`, `--scene`, `--python`, or `--start-pose` to override the
defaults. The MuJoCo bridge reports measured positions and velocities and
accumulates the shared base translation, tilt, height, and contact policy in
`motion/config/stability_limits.yaml`.

## Physical hardware

The Rust transport has been validated on Orion's Raspberry Pi and five-servo
STS3215 bus. Begin a new checkout or hardware change with a torque-off state
snapshot:

```bash
runtime_rust/target/debug/oriond --check \
  --port /dev/ttyACM0 \
  --calibration "$HOME/.config/orion/servo_calibration.json"
```

The hardware lifecycle is `--serve`, `--configure`, `--enable`, motion
commands, then `--disable`.
Neither daemon command is a physical emergency stop; an accessible hardware
torque/power interruption remains required during physical trials.

## Port structure

- `src/transport.rs` — raw `rustypot` STS3215 serial and packet boundary.
- `src/driver.rs` — calibration conversions and servo safety sequence.
- `src/daemon.rs` — backend-independent lifecycle and command state machine.
- `src/socket.rs` — local Unix command server/client.
- `src/pose.rs`, `motion.rs`, `trajectory.rs` — shared motion semantics.
- `src/mujoco.rs` and `mujoco_bridge.py` — native simulation backend.
- `src/main.rs` — `oriond` arguments and 50 Hz control loop.

During development, build and run `oriond` directly from this source tree. It
is not installed as a system service.

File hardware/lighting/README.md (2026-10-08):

# Orion lighting hardware

V1's commissioned light is an Adafruit NeoPixel Shield, product 2864:

- 40 individually addressable SK6812-compatible red-green-blue-white (RGBW)
  pixels.
- Physical 5 by 8 matrix.
- Dedicated approximately 3000 K warm-white channel.
- 8-bit red, green, blue, and white channels.
- 800 kHz single-wire NeoPixel protocol.

V2 selects a 24-pixel RGBW ring with `--hardware v2`, retaining GPIO12, GRBW
encoding and the persistent Pi 5 driver below. The V1 wiring and matrix layout in
the next sections do not apply to the ring. See [V2 calibration and rest capture](../../docs/hardware-versions.md).

The assembled robot reports this direct Raspberry Pi 5 wiring:

```text
Pi physical pin 4  / 5 V   -> shield 5 V
Pi physical pin 30 / ground -> shield ground
Pi physical pin 32 / BCM12 -> shield D6 / DIN
```

V1 head cable allocation. Verify continuity before reconnecting a modified or
replacement cable.

| Conductors | Reported connection |
| --- | --- |
| Orange and white/orange | LED 5 V |
| Brown, white/brown, and white/green | LED ground |
| Solid green | LED data |
| Blue and white/blue | Differential speaker pair; neither conductor is ground |

The assembled robot has no 3.3 V-to-5 V data level shifter. The physical
backend must therefore use BCM12, pulse-width modulation (PWM) channel 0,
non-inverted output, 40 pixels,
and an initial green-red-blue-white (GRBW)/800 kHz configuration.

Physical checks on Orion confirmed a non-serpentine, row-major 8 by 5
matrix. Every row runs left to right, starting at the top:

```text
 0  1  2  3  4  5  6  7
 8  9 10 11 12 13 14 15
16 17 18 19 20 21 22 23
24 25 26 27 28 29 30 31
32 33 34 35 36 37 38 39
```

Therefore a zero-based `(row, column)` coordinate maps directly to
`row * ORION_LIGHT_WIDTH + column`. Confirmed reference points are pixel 0 at
top-left, 7 at top-right, 8 at the second row's left edge, and 39 at
bottom-right.

Checks also confirmed that Orion's logical channel arguments display as
red, green, blue, and warm white respectively. The backend's GRBW wire-order
translation is therefore correct for the installed shield.

The complete 40-pixel frame was verified on the physical robot using the
acknowledgement value `RGBW(8, 3, 0, 20)`, followed by a successful all-off
frame. The persistent module, overlay, PWM channel, and BCM12 pin service were
then verified after a full robot reboot with `verify-persistent.sh`. Physical
lighting output and its boot configuration passed those checks.

The shield is powered from the Pi's 5 V header rather than an independent
supply. The runtime does not impose a brightness ceiling: RGBW values are sent
exactly as requested. Use low values while confirming this particular wiring
and channel order:

```text
all off
pixel 0 red
pixel 0 green
pixel 0 blue
pixel 0 white
low-output 40-pixel chase
```

This sequence establishes channel order, data reliability, pixel count, and
matrix orientation. If the direct 3.3 V data signal produces flicker,
incorrect colours, or intermittent updates, the hardware path requires a
5 V-compatible logic-level shifter; scene or colour code should not compensate
for signalling errors.

## Persistent Raspberry Pi 5 setup

Raspberry Pi 5 support in `rpi_ws281x` uses the RP1 PWM kernel module from its
`pi5` branch. Orion keeps the upstream source outside this repository and owns
the boot installation through `install-persistent.sh`.

Install DKMS, the headers for the running kernel, the headers package that
follows kernel updates, and the device-tree compiler:

```bash
sudo apt install dkms linux-headers-$(uname -r) linux-headers-raspi device-tree-compiler
```

On Raspberry Pi OS, replace `linux-headers-raspi` with the headers package for
your kernel flavour.

On Raspberry Pi OS, install `raspi-utils` for `/usr/bin/pinctrl`. On Ubuntu 24.04,
build the [official Raspberry Pi utility](https://github.com/raspberrypi/utils/blob/master/pinctrl/README.md):

```bash
sudo apt install -y cmake build-essential git
mkdir -p ~/dev
git clone --depth 1 https://github.com/raspberrypi/utils.git ~/dev/orion-pi-utils
cmake -S ~/dev/orion-pi-utils/pinctrl -B ~/dev/orion-pi-utils/build-pinctrl
cmake --build ~/dev/orion-pi-utils/build-pinctrl -j 2
sudo install -m 755 ~/dev/orion-pi-utils/build-pinctrl/pinctrl /usr/bin/pinctrl
sudo groupadd -f gpio
sudo usermod -aG gpio "$USER"
```

Clone the official Pi 5 branch. The installer builds the driver through DKMS
and compiles the device-tree overlay itself:

```bash
cd ~/dev
git clone --branch pi5 --single-branch \
  https://github.com/jgarff/rpi_ws281x.git
```

Install Orion's persistent configuration from the Orion checkout:

```bash
cd ~/dev/orion
sudo hardware/lighting/install-persistent.sh /home/mofe/dev/rpi_ws281x
sudo reboot
```

The installer performs six persistent operations:

1. Registers the driver source with DKMS as `rp1_ws281x_pwm/orion1` under
   `/usr/src/rp1_ws281x_pwm-orion1/`, then builds and installs it for the
   running kernel. When the package manager installs a new kernel, DKMS
   builds the driver for it before that kernel boots. The registered copy
   selects the platform driver's `remove` field by kernel version, because
   upstream targets kernel 6.11 and later and Ubuntu's 6.8 kernel rejects it.
2. Compiles `rp1_ws281x_pwm.dtbo` from the upstream overlay source, installs it
   into the Pi boot overlay directory, and adds `dtoverlay=rp1_ws281x_pwm` to
   `config.txt`. The overlay targets the RP1 node found in the running device
   tree, by its `rp1` label when the base tree provides one. Kernel releases
   name that node differently, and the firmware skips an overlay whose target
   is missing, leaving the module loaded without `/dev/ws281x_pwm`.
3. Configures `rp1_ws281x_pwm` to use PWM channel 0 through
   `/etc/modprobe.d/orion-neopixel.conf`.
4. Loads the module at boot through
   `/etc/modules-load.d/orion-neopixel.conf`.
5. Installs a udev rule granting the Raspberry Pi `gpio` group read/write
   access to `/dev/ws281x_pwm`, so checkout tools can run without root privileges.
6. Enables `orion-neopixel-pin.service`, which assigns BCM12 to RP1 function
   `a0` and verifies that `/dev/ws281x_pwm` exists.

Before changing `config.txt`, the installer preserves its original contents as
`config.txt.orion-backup`. The installer is idempotent and can be rerun.

After the reboot, verify the complete boot contract:

```bash
cd ~/dev/orion
hardware/lighting/verify-persistent.sh
```

Run `id -nG` once to confirm the development user belongs to the `gpio` group.
The verifier requires readable and writable `/dev/ws281x_pwm`, the loaded
module with `pwm_channel=0`, BCM12 configured as `PWM0_CHAN0`, and an enabled
and active pin service. It prints `PASS` only when the complete contract holds.
Run the verifier as the Orion user. On systems where `pinctrl` needs root, the
verifier retries only the GPIO12 state read with `sudo`; device permissions are
still checked as the invoking user. A failed GPIO read prints its diagnostic
instead of exiting silently.

DKMS needs the new kernel's headers to rebuild the driver, which
`linux-headers-raspi` installs with each kernel update. On Ubuntu the installer
refuses to run without that package. To check the driver after a kernel update:

```bash
dkms status rp1_ws281x_pwm
```

Each installed kernel should be listed as `installed`. If one is missing,
install its headers and run `sudo dkms autoinstall -k KERNEL`.

Run the installer once per Pi. Pi deployment runs `verify-persistent.sh` but
not the installer, so a deploy on a Pi without this setup stops with
`/dev/ws281x_pwm is not a character device`. Run the installer, reboot, and
deploy again.

## Orion output checks

Build the Rust runtime on the Pi, then verify the four logical channels with
pixel 0 before lighting the full matrix:

```bash
cargo build --release --manifest-path runtime/Cargo.toml

runtime/target/release/oriond --lights-off
runtime/target/release/oriond --light-pixel 0 8 0 0 0
runtime/target/release/oriond --light-pixel 0 0 8 0 0
runtime/target/release/oriond --light-pixel 0 0 0 8 0
runtime/target/release/oriond --light-pixel 0 0 0 0 8
runtime/target/release/oriond --light 0 0 0 8
runtime/target/release/oriond --lights-off
```

`Pi5NeoPixelDevice` is behind the portable `LightingDevice` interface. It
encodes logical RGBW as GRBW and writes the selected 40- or 24-pixel
RP1 PWM frame to `/dev/ws281x_pwm`. Add `--hardware v2` to the commands above
for the ring. `--lighting-device PATH` can
override that path for diagnostics. These direct commands do not require the
servo daemon and provide direct physical light checks. When the
hardware daemon is active, it owns the device exclusively and scenes become
the normal semantic lighting interface.

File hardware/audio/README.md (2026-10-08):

# Orion audio hardware

V1's commissioned audio board is the Seeed Studio ReSpeaker 2-Mics Pi HAT V2,
a Raspberry Pi Hardware Attached on Top (HAT). Its TLV320AIC3104 codec uses
Inter-Integrated Circuit (I2C) address `0x18`. The HAT provides two microphones
plus playback through its 3.5 mm jack and JST 2.0 speaker output.

V2 selects the XVF3800 USB interface (`Array`) and skips HAT mixer setup.
Use [V2 audio setup](../../docs/hardware-versions.md#usb-capture-and-playback)
to identify firmware channels and test recording/playback. The overlay and mixer
commands below apply to the HAT on the v1 lamp.

Orion uses Seeed's V2 device-tree overlay with the Raspberry Pi kernel's
`snd_soc_tlv320aic3x`, `snd_soc_tlv320aic3x_i2c`, and
`snd_soc_simple_card` modules. The overlay selects the Pi 5 Inter-IC Sound
(I2S) clock-consumer block and registers the stable Advanced Linux Sound
Architecture (ALSA) card name `seeed2micvoicec`. No custom audio kernel module
is installed.

## General-purpose input/output integration

The audio path uses I2C and I2S. The HAT also exposes BCM12 and BCM13 on its
general-purpose input/output (GPIO) Grove digital connector, but the audio
overlay does not claim them. Orion
already owns BCM12 for the 40-pixel NeoPixel shield, so nothing may be attached
to the ReSpeaker Grove digital connector while that lighting wiring is in use.

The HAT's three APA102 LEDs and user button are not used. Orion uses the
40-pixel red-green-blue-white (RGBW) shield as its expressive-light device.

## Persistent Raspberry Pi 5 setup

Install the build and ALSA diagnostic tools:

```bash
sudo apt install device-tree-compiler make alsa-utils i2c-tools
```

Clone Seeed's maintained overlay repository outside Orion, then compile only
the TLV320AIC3104 V2 overlay as the normal development user:

```bash
cd ~/dev
git clone https://github.com/Seeed-Studio/seeed-linux-dtoverlays.git
cd ~/dev/seeed-linux-dtoverlays
make overlays/rpi/respeaker-2mic-v2_0-overlay.dtbo
```

Install Orion's persistent boot configuration:

```bash
cd ~/dev/orion
sudo hardware/audio/install-persistent.sh \
  /home/mofe/dev/seeed-linux-dtoverlays
sudo reboot
```

The installer requires Seeed's V2 overlay targeting the Pi 5 I2S
clock-consumer and TLV320AIC3104 at `0x18`. It installs the compiled overlay,
rejects known conflicting audio overlays, migrates Orion's previous boot
entry to one idempotent `dtoverlay=respeaker-2mic-v2_0` entry, and preserves
the original boot configuration as `config.txt.orion-audio-backup`. It does
not install custom kernel modules.

After reboot, verify the codec, playback, capture, and NeoPixel integration:

```bash
cd ~/dev/orion
hardware/audio/verify-persistent.sh
```

The expected ALSA card name is `seeed2micvoicec`. The verifier also requires
the TLV320AIC3104 at I2C address `0x18` to be bound to its kernel driver. When
Orion's NeoPixel device is present, it confirms BCM12 remains assigned to
PWM0.

## Mixer setup

Orion keeps the confirmed JST-speaker mixer route as a repeatable command
rather than depending on whatever mixer state happened to survive the last
session:

```bash
hardware/audio/configure-playback.sh
```

The script selects `DAC_R1`, sends it through the right line mixer, keeps both
analogue stages at unity gain, and sets PCM to the `0 dB` playback target.
The right differential line output feeds the V2 HAT's mono amplifier and JST
connector; the `HP` controls instead serve the 3.5 mm jack.

The physical playback check uses the stable ALSA name rather than a numeric
card index and sends the tone to the right channel:

```bash
speaker-test \
  -D plughw:CARD=seeed2micvoicec,DEV=0 \
  -c 2 -s 2 -t sine -f 440 -l 1
```

The runtime applies the same mixer contract when its physical WAV backend is
opened, so running from a checkout does not depend on a system boot service or
a globally stored ALSA snapshot.

On Pi desktop installations, WirePlumber can probe the same card after Orion
starts and reset PCM to `-23.5 dB`. Install the supplied
`90-orion-respeaker.conf` under `/etc/wireplumber/wireplumber.conf.d/` during audio
setup to exclude this ReSpeaker device from WirePlumber 0.5. The application
release installer preserves that hardware configuration; it does not create it. Orion's direct
ALSA playback and capture remain available; desktop applications no longer
see this card. HDMI audio is unaffected.

To apply this fix to an existing Pi without rebooting, run as the desktop user
from the Orion checkout:

```bash
sudo install -D -m 0644 hardware/audio/90-orion-respeaker.conf \
  /etc/wireplumber/wireplumber.conf.d/90-orion-respeaker.conf
systemctl --user restart wireplumber
hardware/audio/configure-playback.sh
```

Check that `amixer -c seeed2micvoicec sget PCM` reports `0.00dB` on both
channels and that `wpctl status -n` does not list the ReSpeaker device
`alsa_card.platform-soc_107c000000_sound`. The device-name match is specific
to the installed Pi 5 overlay; recheck it when changing boards or overlays.

Orion also keeps the confirmed dual-microphone capture route as a repeatable
command:

```bash
hardware/audio/configure-capture.sh
```

The script selects the HAT's single-ended `LINE1L` and `LINE1R` microphone
routes, disables the codec's automatic gain control (AGC), and applies a fixed
programmable-gain amplifier (PGA) capture gain. `ORION_CAPTURE_GAIN_DB` accepts
the range documented in [listener configuration](../../docs/configuration.md#pi-runtime-and-listener).
The managed listener supplies its own gain override. The listener configures routing before opening `arecord`, discards
300 ms, reapplies the gain after the ADC starts, then discards another 300 ms.
Reapplying gain prevents ADC startup from undoing the chosen setting. Direct
recording tests can run the script explicitly. Earlier wake tests found reliable
detection at 50 dB but degraded detection at the codec's 59.5 dB maximum through
noise or clipping. The managed voice stack uses the lower configured gain after
further speech trials. Codec AGC remains disabled.

## Hardware checks

The assembled Pi 5 passed the persistent V2 verification with playback and
capture registered as `seeed2micvoicec`, while BCM12 remained assigned to the
NeoPixel pulse-width modulation (PWM) output. The JST route produced the 440 Hz
right-channel test tone,
the direct cue command played Orion's local chime, and both expressive
acknowledgement scenes exercised that ReSpeaker playback path successfully.
The playback target is `0 dB`; listening checks must
confirm that speech is clear without audible clipping at the assembled JST
speaker.

## Stereo voice capture

The Pi Rustpotter listener requests synchronized stereo PCM16 at 16 kHz,
retains stereo for coarse direction estimates, and downmixes to mono for wake
and ASR. Stereo channel independence, orientation and direction accuracy still
require physical checks; see [Pi voice setup](../../voice/README.md).

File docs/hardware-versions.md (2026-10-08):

# Orion hardware versions and V2 calibration

Start V2 setup with Orion's existing servo calibration and rest capture.
`--hardware v1` and `--hardware v2` select separate repository resources and
Pi calibration files. V1's asset values are unchanged.

## Calibrate V2 first

Run from the Orion checkout on the Pi, with the installed runtime stopped:

```bash
uv sync --project hardware/servo_setup --locked
uv run --project hardware/servo_setup orion-verify-servos --hardware v2 \
  --port /dev/ttyACM0
uv run --project hardware/servo_setup orion-calibrate-servos --hardware v2 \
  --port /dev/ttyACM0
uv run --project hardware/servo_setup orion-centre-servos --hardware v2 \
  --port /dev/ttyACM0
uv run --project hardware/servo_setup orion-capture-rest --hardware v2 \
  --port /dev/ttyACM0
```

Centring writes each servo's persistent homing offset so no joint range crosses
raw 0/4095, which the STS3215 cannot command across. `oriond` refuses a
calibration that crosses it; see
[centre the servos](../hardware/servo_setup/README.md#centre-the-servos-when-a-range-crosses-raw-04095).

Use the actual serial port. Calibration uses the same torque-off zero and range
capture as V1, including its existing endpoint margins and backups. Rest capture
uses the same unsupported stability check and writes the measured rest pose.

V2 calibration writes `~/.config/orion/servo_calibration-v2.json`. V2 rest capture
writes `rest` directly into the repository's `motion/config/v2/poses.yaml`, matching
V1's repository pose workflow. Home and rest in that file use the V2 lamp's
captured physical calibration zero. Other poses and motions remain preview
candidates until checked on the assembled lamp. The captured calibration supplies
servo IDs, encoder zeros, directions and numerical limits to the V2 runtime.

V2 hardware, simulation, Studio preview and release validation read the same
repository resources: `motion/config/v2/poses.yaml`, `motion/motions/v2` and
`scenes/v2`. Edit those resources locally, commit and push, then pull
on the Pi. Rest recapture changes the repository pose file; commit that measured
change before pulling subsequent edits. Servo calibration stays on the Pi.

Encoder direction defaults to `+1`, as in the existing V1 capture. Check the
fitted mechanism against the model's positive axes and set any reversed joint's
`encoder_direction` to `-1`. The optional `--directions FILE` argument supplies
those numerical values during capture. Home and other motion poses must use
these measured zeros and ranges; CAD geometry cannot supply encoder zeros.

## Select the hardware profile

Profiles live in `hardware/profiles/v1.json` and `hardware/profiles/v2.json`.
They select LED/audio interfaces, calibration filenames and asset paths. The
runtime reads the selected calibration file; it does not manufacture calibration
values from CAD.

| Interface | V1 | V2 |
| --- | --- | --- |
| LED | 40-pixel RGBW matrix | 24-pixel RGBW ring |
| LED driver | GPIO12, RP1 PWM, GRBW | Same GPIO12 driver |
| Audio | ReSpeaker 2-Mics V2 HAT, `seeed2micvoicec` | XVF3800 USB, `Array` |
| Calibration | `servo_calibration.json` | `servo_calibration-v2.json` |
| Poses | `motion/config/v1/poses.yaml` | `motion/config/v2/poses.yaml` |
| Motions | `motion/motions/v1/` | `motion/motions/v2/` |
| User poses | `motion/user/poses/v1/` | `motion/user/poses/v2/` |
| Scenes | `scenes/v1/` | `scenes/v2/` |
| Simulation | `simulation/mujoco/scene.xml` | `simulation/mujoco/v2/scene.xml` |

The V2 mechanical tree is base → shoulder → elbow → wrist → neck. Existing API
keys remain stable:

| Expected servo ID | API key | V2 mechanism |
| --- | --- | --- |
| 1 | `base_yaw_joint` | Base yaw |
| 2 | `shoulder_pitch_joint` | Shoulder pitch |
| 3 | `elbow_pitch_joint` | Elbow pitch |
| 4 | `head_pitch_joint` | Wrist pitch |
| 5 | `head_roll_joint` | Neck swivel |

V2 numbers its servos along its own chain, so servo 4 is the wrist pitch and
servo 5 the neck swivel; V1's servo 4 was its wrist roll. The runtime refuses a
calibration whose servo IDs differ from this map. The zero-pose model rotates pitch about +X and
yaw and swivel about −Z, so negative yaw or swivel turns toward the lamp's own
left, matching the hardware. Angles
use radians and model geometry uses metres.

With `encoder_direction: 1`, the fitted V2 joints move as follows:

| API key | Negative | Positive |
| --- | --- | --- |
| `base_yaw_joint` | Turns to the lamp's left | Turns to the lamp's right |
| `shoulder_pitch_joint` | Leans back | Leans forward |
| `elbow_pitch_joint` | Raises the forearm | Lowers the forearm |
| `head_pitch_joint` | Tilts the head up | Tilts the head down |
| `head_roll_joint` | Turns the head to its left | Turns the head to its right |

V2 poses keep V1's arm and head-pitch offsets from home. V1's `head_roll` was a
wrist roll used as a constant head cock; on V2 the neck swivel instead leads
each turn in the base's direction at half its angle.

Read calibrated hardware state without enabling torque:

```bash
runtime/target/release/oriond --hardware v2 --check --port /dev/ttyACM0
```

For motion development, use `--serve --hardware v2 --character-on-start off`
and the existing [hardware lifecycle](../runtime/README.md#physical-hardware).
V2 does not inherit V1's measured gravity-gain overrides.

## LED and USB audio setup

Reuse the [persistent GPIO12 installation](../hardware/lighting/README.md#persistent-raspberry-pi-5-setup)
for the ring. Verify it after reboot with `hardware/lighting/verify-persistent.sh`.
DKMS rebuilds the module for each installed kernel. Add `--hardware v2` to Orion's direct
light/audio checks for the 24-pixel ring and USB playback.

### USB capture and playback

The V2 profile captures the XVF3800's two-channel stream and uses processed
channel 0. The listener accepts `--capture-channels 2|6 --processed-channel N`
for other firmware layouts; see the
[Seeed USB guide](https://wiki.seeedstudio.com/respeaker_xvf3800_introduction/).
V2 skips HAT mixer commands and raw-microphone direction estimation. Calibrated
beam-based attention is opt-in; see [listener settings](configuration.md#pi-runtime-and-listener).

The Orion service user needs one-time access to the read-only USB control
interface. Install the [XVF3800 udev rule](../voice/README.md#measure-the-xvf3800-on-v2),
add the service user to `plugdev` (`sudo usermod -aG plugdev USER`), and restart
the listener so it picks up the group. Audio capture can work without this
permission while direction reads fail. This setup is separate from release installation.

The XVF3800 playback controls `PCM,0` and `PCM,1` default to -20 dB. `oriond`
sets both to 0 dB at startup. To set them by hand:

```bash
amixer -c Array sset PCM,0 0dB unmute; amixer -c Array sset PCM,1 0dB unmute
```

## CAD, URDF and MuJoCo

The V2.1 R4/R2 model is packaged with 33 portable visual meshes and a matching
`description/urdf/orion-v2.urdf`. A second CAD-to-URDF conversion is unnecessary
for geometry preview. Run the profile-aware daemon with
`--serve --backend mujoco --hardware v2`.

The model uses fixed-base kinematic tracking. Its metrics report
`validation_scope: "kinematic_preview"` and do not certify balance, collisions
or motor tracking. Existing standalone calibrated editors retain V1 assumptions.

`simulation/mujoco/v2/mass-properties.json` records CAD-derived centres and
inertias at a PLA density of 1.24 g/cm³. Printed defaults are solid PLA equivalents;
actual print weights depend on walls, infill and skins. Supplier masses use
explicit assumptions, and missing electronics, fasteners and cables are listed.
Use slicer part weights excluding supports, or measured weights, to improve them.

```bash
.venv/bin/python scripts/import_v2_model.py
.venv/bin/python scripts/estimate_v2_inertias.py --inputs /path/to/mass-inputs.json
```

The optional input follows `simulation/mujoco/v2/mass-inputs.example.json`:
`part_masses_g` maps mesh filenames to masses in grams; `extra_components` supplies
`name`, `body`, `mass_g`, `centre_m` and `size_m` for omitted hardware. Centres are
body-local and sizes are box dimensions in metres. Both URDF and MJCF receive the
same link mass, centre and inertia. Contacts and complete assembly dynamics
remain additional modelling work.

## Deploy the selected version

After calibration, centring and motion validation, deploy with
`--hardware v2` using the [Pi deployment procedure](quickstart.md#deploy-to-the-pi).
The installer validates calibration and compiles motions against its limits
before switching services. V2, like V1, starts in character mode; pass
`--character-on-start off` to a manually started `oriond` for maintenance.
The camera pipeline is not implemented.

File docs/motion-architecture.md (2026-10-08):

# How Orion moves

Orion is a lamp with five servo joints. A request such as "acknowledge the
person on the left" becomes a short sequence of named poses. The Rust runtime
(`oriond`) turns that sequence into one smooth trajectory and sends joint goals
to the servos 50 times a second. Exact schemas, constants and the animation
catalogue are in the [motion reference](motion-reference.md).

## Key terms

| Term | Meaning |
| --- | --- |
| Joint | One of five servos: `base_yaw_joint`, `shoulder_pitch_joint`, `elbow_pitch_joint`, `head_roll_joint`, `head_pitch_joint`. Angles are radians. |
| Pose | A named target for all five joints, such as `home` or `look_left`. |
| Motion | An ordered list of keyframes. Each keyframe names a pose (absolute motion) or offsets from an anchor (anchor-relative motion). |
| Anchor | A complete measured pose that idle and speech animation move around and always return to. Animation never moves the anchor itself. |
| Arrival | How a keyframe is reached. `through` keeps moving through it; `settle` stops there with zero velocity. |
| Style | Named timing character (tempo, smoothness, amplitude). Styles never change safety limits. |
| Scene | A motion plus light and sound, run on one clock and synchronised by motion markers. |
| Settling | After a motion's timeline ends, the runtime waits until measured feedback is still and on target before reporting `completed`. |

## From request to servo

```text
User, voice or Studio request
        │  names a pose, motion, scene or character state
        ▼
Character or scene coordinator      decides what may run now
        ▼
Motion definition                   absolute poses, or offsets around an anchor
        ▼
MotionSequence                      resolves targets, one uniform scale, markers
        ▼
CompiledTrajectory                  quintic position/velocity/acceleration curves
        ▼
RuntimeCore, every 20 ms            read feedback → sample → write all five goals
        ▼
Driver                              calibration check, radians ↔ servo encoder
        ▼
STS3215 servos   or   MuJoCo simulator
```

1. **A request names a capability.** Studio talks to the authenticated gateway,
   which sends a command over the Pi's local Unix socket. Commands name a pose,
   motion, scene or character state. They cannot contain raw servo writes or
   arbitrary joint streams.
2. **The runtime picks a start state.** A new movement starts from the latest
   measured position and velocity. Speech continuations instead start from the
   commanded position, velocity and acceleration, so each extension does not
   restart from lagging feedback.
3. **Targets are resolved.** Absolute keyframes use their named pose.
   Anchor-relative keyframes add their offsets to the immutable anchor. If the
   offsets would leave the calibrated range, the whole clip is scaled down by
   one factor, which keeps its shape.
4. **The whole action is compiled at once.** The compiler sees every remaining
   keyframe, so velocity carries smoothly through `through` keyframes instead of
   easing to a stop at each one. It then removes unrequested overshoot, slows
   only segments that would exceed the servo's speed, and checks every 20 ms
   sample against calibration.
5. **`RuntimeCore` executes at 50 Hz.** Each cycle reads all joint feedback,
   samples the trajectory, writes one synchronised goal packet for all five
   joints, and publishes status.
6. **Measured feedback decides completion.** When the timeline ends the run
   moves to `settling`. It becomes `completed` only after every joint stays
   within position and velocity tolerance for the settle window, or
   `timed_out` if it never does. `stop` produces `cancelled`.

The hardware and MuJoCo backends implement the same `RuntimeDriver` interface
and receive the same joint samples. MuJoCo is a physics backend, not a second
animation system.

## Why the movement looks fluid

- Authors use a few readable poses rather than dense motor samples.
- Internal keyframes use `through` unless a stop is part of the acting.
- The compiler shares velocity and acceleration across those keyframes.
- Joints get slightly different path character, so they do not move in lockstep.
- Coordinated joints trace curved arcs with the head.
- Speech is one continuous motion run that extends as audio arrives and
  settles once at the end.
- Supporting joints follow the main action instead of oscillating on their own.

A joint can briefly reach zero velocity when it reverses direction. The
compiler never inserts a held stop unless the keyframe says `settle`.

## Character mode

`oriond` starts character mode after it initialises, on V1 and V2.
`--character-on-start off` is the maintenance override. Startup configures the
servos, enables holding torque, moves to `home` and captures the anchor. Only a
measured arrival at home enters idle; a cancelled or timed-out start leaves
character mode off.

```text
Off ── character start ──▶ Starting ── home completed ──▶ HomeIdle
                                                             │ held elsewhere
                                                             ▼
                                                          PoseIdle
                                          ┌─────────────────┼─────────────────┐
                                          ▼                 ▼                 ▼
                                      Listening         Thinking          Speaking
                                          └─────────────────┴───────┬─────────┘
                                                                    ▼
                                                           ForegroundScene
                                                                    ▼
                                                     Settling ──▶ HomeIdle / PoseIdle

Any enabled state ── character stop ──▶ ShuttingDown ──▶ Off
```

Stopping character mode cancels owned scene and speech work, returns home,
clears character lighting and leaves holding torque on. Moving to the
mechanical `rest` pose and releasing torque are separate steps, sequenced by
the [automatic rest coordinator](system-architecture.md#automatic-rest-and-waking).

### Who wins when behaviours compete

1. Shutdown, cancellation and torque release.
2. An explicit foreground scene or motion.
3. Speech.
4. Listening or thinking reactions.
5. Autonomous idle.
6. Background idle lighting.

The scene coordinator owns scene tracks, the speech coordinator owns audio
playback, and the character coordinator owns the anchor, idle schedule and
generated speech motion. `RuntimeCore` is the only thing that executes
movement for all three.

### Anchors

The anchor is captured when Orion enters an idle context. Every idle and speech
clip is resolved from it:

```text
target[joint] = anchor[joint] + style_amplitude × uniform_scale × offset[joint]
```

Each clip ends with a zero-offset `settle`, so it returns exactly to the
anchor. Offsets never accumulate, and recovery after an interruption is
predictable. A completed foreground scene, or a direct foreground motion that
ends holding, sets the next anchor from the measured pose. Speech, reactions,
idle, and failed or cancelled scenes never change it.

### Idle

Two independent randomised timers pick the next idle: a micro idle every 8–20
seconds and a larger idle every 35–75 seconds. The anchor pose's
`idle_profile` chooses suitable clips; directional poses avoid yaw clips that
would push into a range limit. Each play varies direction, amplitude and tempo
slightly from a seeded random generator, never repeats the previous clip, and
plays no sound. Background light comes from the anchor pose's
`default_lighting`.

### Thinking and speech

Repeated thinking requests during one voice turn keep the current thinking
movement instead of restarting it. When speech takes over, motion continues
from the commanded thinking state.

Speech animation is driven by the reply audio. The runtime measures loudness in
20 ms frames, finds quiet gaps and phrase peaks, and plans one head-led
performance:

- every phrase leads with the head, and the shoulder and elbow follow later;
- emphasis nods land just before loud peaks;
- a larger body beat appears only on strong, well-spaced peaks;
- quiet gaps can hold the current phrase pose;
- the performance ends with one settle at the anchor.

Long or streamed replies are planned in pieces and extend the same motion run
as audio arrives. Speech motion is best effort: if it fails to plan, the audio
still plays. If audio fails, the motion settles back to the anchor. The exact
values are in the [speech performance policy](motion-reference.md#speech-performance-policy).

### Voice attention

Confirmed voice sessions can request small absolute turns toward the speaker
(`attention_left` and `attention_right`). The
[runtime attention contract](../runtime/README.md#character-startup-and-voice-attention)
covers their anchor, return timing and interruption.

## Failure containment

- A speech motion failure does not silence speech.
- An audio failure cancels speech animation and settles to the anchor.
- An idle timeout is diagnostic and does not turn character mode off.
- A scene movement timeout ends the scene and stops its audio.
- Invalid assets fail loading or reload before anything moves.
- Targets outside calibration are rejected before any servo command.
- Activation copies present positions into the goal registers before enabling
  torque, so the arm does not jump.
- A few missed servo replies are tolerated; sustained bus failure cancels the
  movement and reports `bus_fault` while the daemon keeps serving.

## Designing animation

Orion should feel calm, curious, warm and attentive: alive enough to read
intent, restrained enough not to compete with the conversation. The governing
rule is one primary idea at a time. Six qualities guide every design:

- **Ease:** begin, travel and settle without harshness.
- **Legibility:** the target, state or acknowledgement is easy to read.
- **Economy:** use the smallest movement, light or sound that works.
- **Grounding:** expression follows real runtime state, not decorative randomness.
- **Natural timing:** pauses and overlap feel intentional but remain testable.
- **Temperament:** calm and competent rather than hyperactive.

The classic animation principles map onto Orion like this:

| Principle | How Orion applies it |
| --- | --- |
| Squash and stretch | Shoulder and elbow close the silhouette before an opening or lift |
| Anticipation | Expressive turns start with a small opposite yaw |
| Staging | One joint group leads; light and sound land on the same beat |
| Pose to pose | Named poses for actions; idle and speech vary approved shapes |
| Follow-through and overlap | Supporting joints arrive after the lead; speech delays the body after the head |
| Slow in and slow out | The compiler shares derivatives at `through` and stops only at `settle` |
| Arcs | Joints are reviewed together in MuJoCo and on hardware |
| Secondary action | Small elbow follow, counter-tilt or light supports the main idea |
| Timing | Styles change tempo, smoothness, amplitude and settle weight |
| Exaggeration | Authored overshoot and emphasis nods stay within calibration |
| Solid drawing | Every held pose is checked from useful angles under gravity |
| Appeal | Asymmetry, warm cues, a forward eyeline and purposeful stillness |

Before adding an asset, answer:

1. What is the single idea and which joints lead it?
2. Which silhouette must read at the main drawing?
3. What anticipation announces it?
4. Which joints follow, and how do they stay secondary?
5. Where is a real `settle` justified?
6. Does it trace a coordinated arc?
7. How does timing express weight?
8. Which anchors must support it?
9. What happens on interruption, timeout or cancellation?
10. What MuJoCo and physical checks show the acting reads?

Add the asset to the [animation catalogue](motion-reference.md#animation-catalogue)
in the same change.

## How it is validated

- **Schema checks** reject incomplete or ambiguous poses, motions and scenes.
- **Compiler tests** check continuity, exact targets, speed retiming,
  calibration containment and interruption.
- **Catalogue tests** compile every built-in pose and motion against calibration.
- **Native MuJoCo tests** run the real daemon against the physics backend.
- **Physical review** covers what joint-space tests cannot: silhouette, timing,
  cable clearance, sound, light and appeal.

## Where the code lives

| Concern | Source |
| --- | --- |
| Poses | `runtime/src/motion/pose.rs` |
| Motions, relative resolution, amplitude scaling | `runtime/src/motion/library.rs` |
| Styles | `runtime/src/motion/style.rs` |
| Trajectory compiler | `runtime/src/motion/trajectory.rs` |
| Movement lifecycle and 50 Hz sampling | `runtime/src/control/core.rs` |
| Character state, idle, speech performance | `runtime/src/expression/character.rs` |
| Speech audio and energy analysis | `runtime/src/expression/speech.rs` |
| Scenes and markers | `runtime/src/expression/scene.rs` |
| Daemon loop and command priority | `runtime/src/app/server.rs`, `runtime/src/app/commands.rs` |
| Calibration and radians conversion | `runtime/src/motion/calibration.rs`, `runtime/src/devices/sts3215/driver.rs` |
| Servo packets | `runtime/src/devices/sts3215/transport.rs` |

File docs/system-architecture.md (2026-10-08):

# Orion system architecture

Orion's Raspberry Pi runs microphone capture, speech recognition, speech
synthesis, the agent coordinator, and the hardware runtime. Studio connects to
the Pi for editing, controls, settings, and observation. Codex App Server runs
on the Pi, while Codex model inference and web search use online services.

## System boundary

```mermaid
flowchart LR
    studio[Studio desktop app]
    cloud[Online Codex inference and search]
    subgraph pi[Raspberry Pi]
        listener[Listener: Rustpotter and Silero]
        host[Orion service: coordinator and agent]
        asr[Qwen ASR worker]
        tts[Piper Alba TTS worker]
        codex[Codex App Server]
        gateway[Authenticated gateway]
        runtime[oriond: movement, light and playback]
        listener <-->|Local WebSocket| host
        host <-->|Private pipes| asr
        host <-->|Private pipes| tts
        host <-->|Private pipes| codex
        host -->|Local HTTP: speech and lamp requests| gateway
        gateway <-->|Local service RPC| host
        gateway <-->|Private Unix socket| runtime
        listener -->|Voice session events| runtime
    end
    studio <-->|Authenticated HTTP| gateway
    codex <--> cloud
```

The Pi uses four systemd services. Their processes have separate responsibilities
so model execution and network waits stay outside the 50 Hz movement loop.

| Service | Responsibility |
| --- | --- |
| `oriond` | Servos, movement completion, character animation, RGBW output and speaker playback |
| `orion-listener` | Microphone capture, Rustpotter wake candidates, Silero speech boundaries and voice-session state |
| `orion-voice-stack` | Runs `orion-service`, which owns the coordinator, agent, speech workers and saved voice settings |
| `orion-studio-gateway` | Authenticates requests, manages asset publication, forwards service controls and spools response audio |

The hardware and MuJoCo backends use the same movement lifecycle and trajectory
compiler. Each backend supplies its own joint feedback. See the
[motion architecture](motion-architecture.md) for execution details.

## Authority boundaries

### Hardware runtime

`oriond` owns the servo bus, RGBW device and audio playback (the ReSpeaker HAT on V1, the XVF3800 on V2). It applies
calibration, compiles trajectories, checks measured movement completion, and
coordinates scenes, speech animation, idle behavior, rest and scheduled alerts. Clients
submit named poses, motions, scenes or other supported operations. Every movement
passes through the runtime's limits and ownership checks.

### Listener and voice service

The listener keeps microphone capture open unless the saved mute setting disables
it. Rustpotter detects a possible wake phrase, registers a session, and plays the
candidate chime and light pulse. The coordinator verifies a short recording with Qwen while the
listener continues recording the command. Silero decides when speech has ended.

`orion-service` owns one agent executor and a restartable voice coordinator. The
coordinator sends inference jobs to separate ASR and TTS workers, calls the agent
through Rust channels, uploads reply audio, and waits for playback completion.
Keeping the agent alive across an idle coordinator restart preserves the
conversation. Restarting the service starts a fresh conversation and retains
saved memory and personality.

A confirmed command reaches Codex as text. The available agent tools support web
search, explicit memory operations, validated lamp and mode changes, sleep, timers
and alarms. Character motion
comes from runtime behavior or explicit user controls. See the
[voice architecture](voice-architecture.md) for capture, conversation and playback
ordering.

### Gateway

The gateway exposes versioned operations for assets, movement, lighting, speech,
settings and status. Hardware requests use `/tmp/oriond.sock`. Voice settings and
observation use the service's private loopback RPC connection. The onboard
coordinator also reaches the gateway over loopback to upload speech and apply
lamp changes.

Remote access uses a bearer token over HTTP and assumes a trusted local network.
The listener restricts its processing connection to loopback; authenticated
control clients can still inspect or change microphone mute. The service's
private credentials stay on the Pi.

### Studio

Studio owns asset browsing, editing, previews and its connection to the gateway.
It stores desktop pairing credentials and local UI preferences. Voice settings,
agent personality, memories and microphone mute are saved on the Pi. Studio polls
bounded event snapshots for transcripts, model information and timing.

Editing a draft changes the preview. Publishing or choosing an explicit robot
control sends a request to the Pi. The connected runtime compiles movement
previews against its calibration. Static model previews do not show live joint
telemetry.

## Assets and installed releases

The deployment builds runtime, gateway, listener and voice-service code from one
Git commit in a separate release directory. Python environments belong to that
release. Shared model files and native inference tools live under
`~/.local/share/orion/voice-stack/`.

The runtime and gateway keep the existing catalog root, normally
`/home/mofe/dev/orion`. It contains the calibrated pose library, motion definitions,
scenes, audio cues and user assets. Activation updates built-in pose, motion and
scene YAML from the same Git commit as the executables. Calibration remains in
the Pi user's configuration directory, and user-authored assets remain in their
separate catalog directories.

The installer records managed built-in paths in
`~/.local/share/orion/voice-stack/catalog-assets.json`. The first update derives
retired paths from the checkout's tracked YAML; later updates use that inventory.
It snapshots overwritten and removed files in the service-switch transaction so
rollback restores both code configuration and YAML. Git HEAD and the index are
unchanged. Local edits to built-ins are replaced; untracked local assets remain.

User poses, motions and scenes live in `motion/user/poses/<version>/`,
`motion/motions/<version>/user/` and `scenes/<version>/user/`, with `version`
selected as `v1` or `v2`. The gateway stages published changes,
asks `oriond` to validate and reload the catalog, and restores the previous files
if reload fails. Built-in names cannot be shadowed. Standalone user poses and
motions use a new name for changed content. Updating or deleting a user scene
requires the content revision that Studio loaded.

The [quickstart](quickstart.md#deploy-to-the-pi) describes preparation, activation,
readiness checks and rollback. [Configuration](configuration.md) identifies saved
settings and the paths that each release manages.

## Runtime state

Movement follows this lifecycle:

```text
executing -> settling -> completed
                      \-> timed_out
executing/settling ----> cancelled
```

Scenes coordinate movement, lighting and audio under one monotonic clock. They
finish after their dispatched work reaches a terminal result. Runtime status
keeps the active movement and most recent terminal movement. Run IDs and retained
results reset when the daemon restarts.

Daemon startup enables character mode by default: it configures the servos,
enables holding torque and moves home. Measured arrival establishes an anchor
for idle and speech animation. Foreground motion or scenes take priority over
speech, listening or thinking reactions, and idle. Repeated thinking events keep
the existing gesture running; a change from transcription to agent processing
does not replay its opening tilt.

Studio's **Stop character** cancels owned work, returns home and leaves torque
holding. Character behavior resumes after an explicit start or a daemon restart
with character mode enabled. `--character-on-start off` starts maintenance mode
with torque disabled. Microphone mute has its own saved setting.

## Automatic rest and waking

Idle mode arms the inactivity timer after successful homing. The default interval
is 30 minutes. Lamp mode keeps the same idle animations and disables automatic
rest. Selecting idle mode starts a fresh inactivity interval. The selected mode
survives service restarts and code deployments. Each voice session can reset the
deadline once through an accepted
Qwen wake confirmation. Candidates, rejected wakes and ordinary animation do
not reset it.

An active confirmed conversation, including the follow-up listening window,
defers rest. Foreground movement, scenes, queued or playing speech, and speech
settling also defer it. Once that work finishes, an expired deadline can start
rest immediately. Background idle and unconfirmed thinking can yield to rest.

The rest coordinator tracks the descent by movement run ID and releases torque
only after measured completion. A timeout, cancellation, missing result or failed
torque release enters `fault`. A failed home movement during waking also enters
`fault`. Automatic waking and voice reply playback then await explicit recovery.

At mechanical rest, a wake candidate plays the acknowledgement chime and a
brief light pulse while the body remains still. Qwen confirmation starts the
return home. If confirmation arrives during descent, Orion finishes descending and then
returns home while retaining torque. Capture continues during both movements.
After home completes, the runtime applies the latest listening or thinking state
and checks any direction evidence before turning toward the speaker.

Studio's **Go to rest** starts this sequence immediately. The `go_to_sleep` agent
tool queues rest behind its spoken acknowledgement and closes the voice session
without a follow-up window. Explicit sleep works in either mode and keeps the
selected mode for the next wake. Explicit Stop,
`disable`, and maintenance startup disable automatic waking; an explicit character
start rearms it. The lower-level `goto rest` command moves the body and requires
a separate torque-release command after verified arrival. See
[confirmed waking](voice-architecture.md#confirmed-waking) for reply ordering.
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

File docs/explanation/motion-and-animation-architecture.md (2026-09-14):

# Motion and animation architecture

Orion separates **what the character intends to do** from **how the motors are
commanded**. The character or scene layer selects a semantic action such as
“acknowledge the person on the left.” The Rust runtime resolves that action
into joint-space waypoints, compiles the whole action into one continuous
trajectory, and samples it at 50 Hz. Only the hardware driver knows how radians
map to STS3215 servo encoder values.

That separation is the central architectural rule. Character code never writes
servo registers, and the servo layer never decides which expression Orion
should perform.

## The motion stack

An **immutable anchor** is a complete measured pose that idle and speech
animation use as a fixed reference. Relative animation may move away from the
anchor, but it cannot move the reference itself.
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

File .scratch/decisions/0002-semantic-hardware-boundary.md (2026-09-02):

# 0002: Expose semantic capabilities, not raw hardware

- **Status:** Accepted
- **Scope:** Studio, agents, gateway, and physical devices

## Context

Desktop tools and intelligent agents need to request useful behaviour without
gaining enough authority to bypass calibration, limits, lifecycle, or device
ownership. Raw joint streams, servo registers, GPIO writes, and arbitrary file
paths would make that guarantee impossible to audit.

## Decision

Keep the serial bus, RGBW output, and Pi playback devices under `oriond`.
Expose allow-listed named poses, motions, scenes, speech, status, cancellation,
and revision-checked asset operations through the Studio gateway.
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

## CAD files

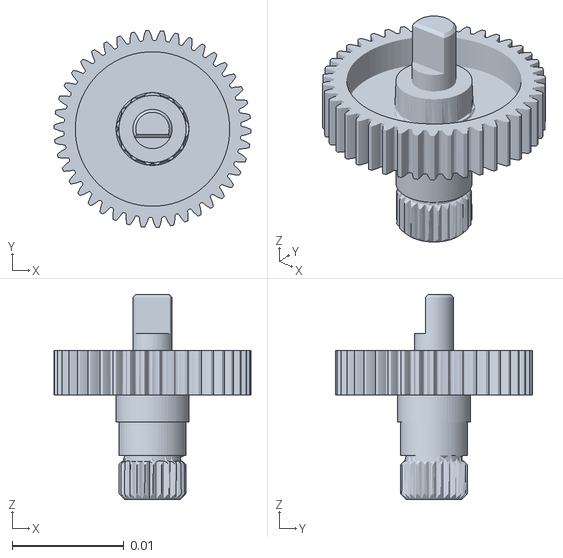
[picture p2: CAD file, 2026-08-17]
description/meshes/ge_27.stl
0.0176 x 0.0176 x 0.0183

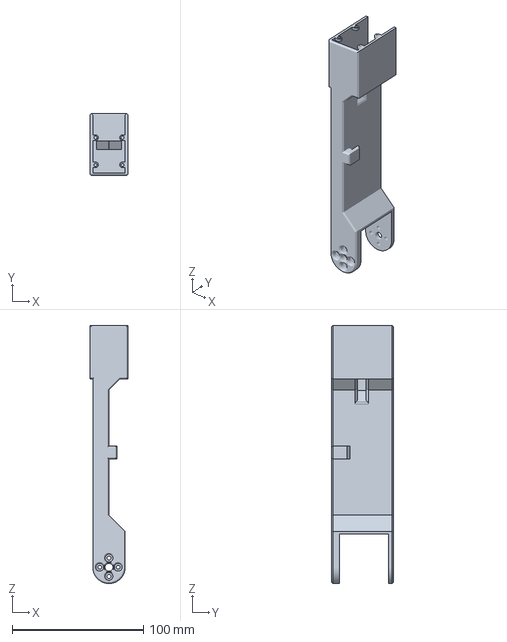
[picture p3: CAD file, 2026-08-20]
hardware/reference_lelamp/original_3mf/LampArm (Elbow-Wrist).3mf
28.7 x 47.2 x 196.3 mm

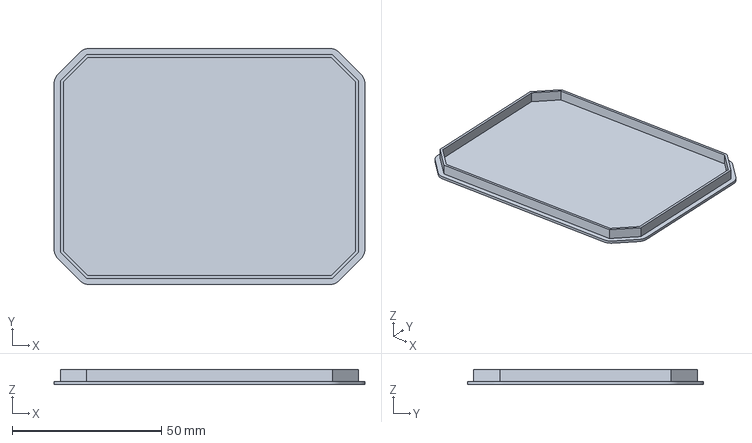
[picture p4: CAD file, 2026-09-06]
hardware/reference_lelamp/print_ready_mm/LampHead - Diffuser.3mf
104.2 x 79.2 x 5.00 mm

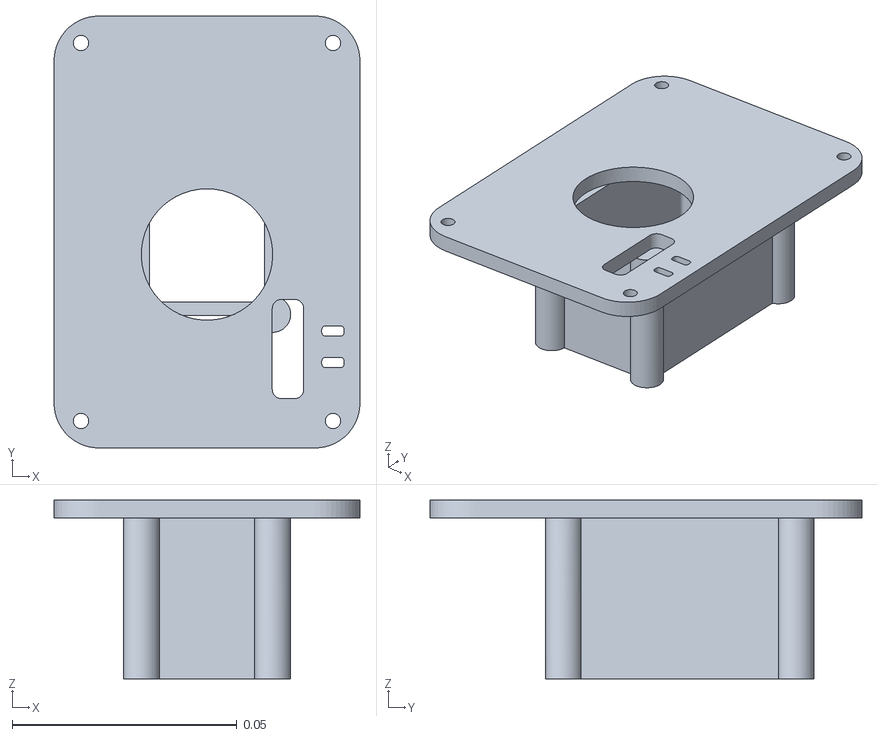
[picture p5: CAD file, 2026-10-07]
simulation/mujoco/v2/meshes/v21_04_Yaw_servo_carrier.stl
0.068 x 0.096 x 0.0397

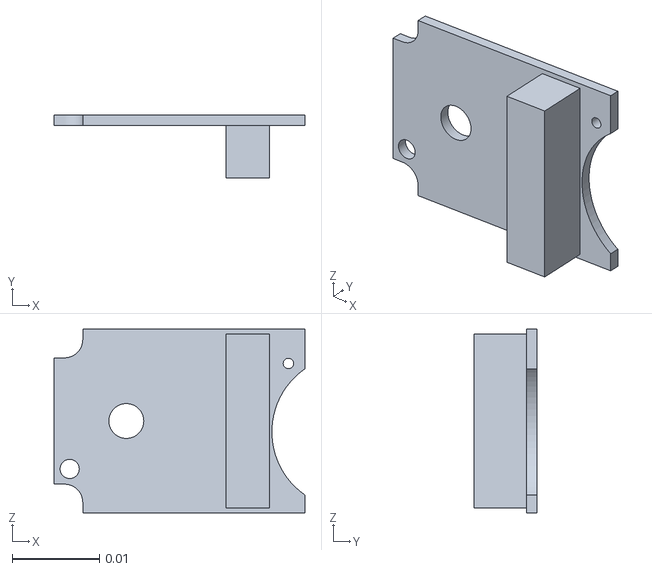
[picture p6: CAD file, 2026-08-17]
description/meshes/pcb_chazuo_92.stl
0.0288 x 0.0072 x 0.0211

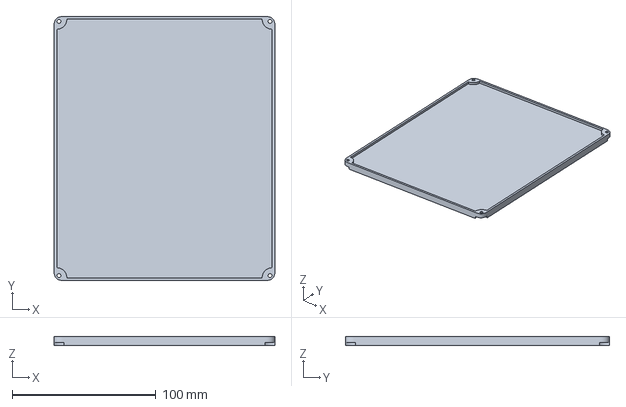
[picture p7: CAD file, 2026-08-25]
hardware/reference_lelamp/print_ready_mm/LampBase - Lamp Base Cover.3mf
153.8 x 183.8 x 6.00 mm

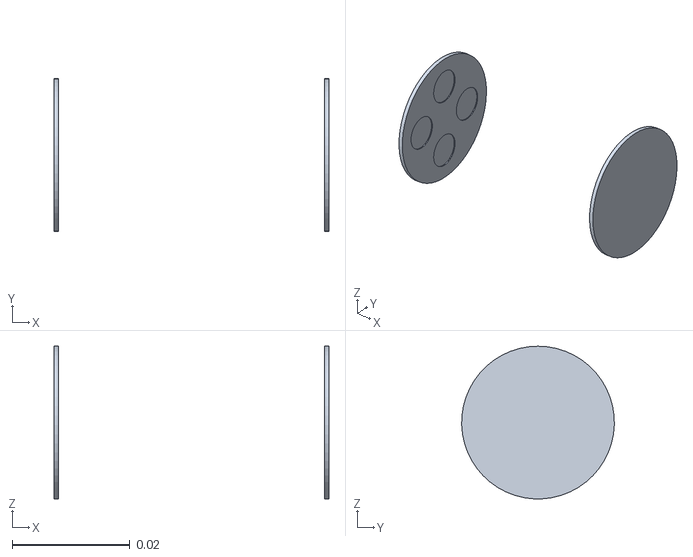
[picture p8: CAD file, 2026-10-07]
simulation/mujoco/v2/meshes/v21_22_elbow_flush_horn_caps.stl
0.0468 x 0.026 x 0.026

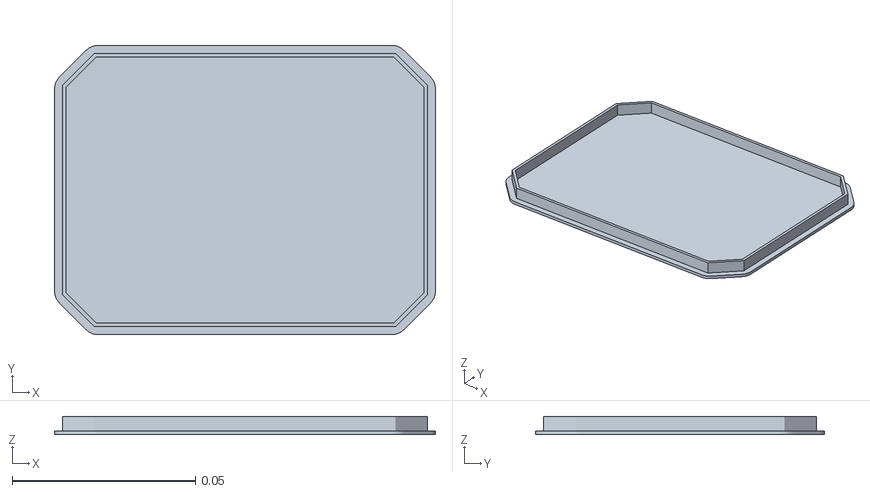
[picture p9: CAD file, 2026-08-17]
description/meshes/diffuser.stl
0.104 x 0.079 x 0.005

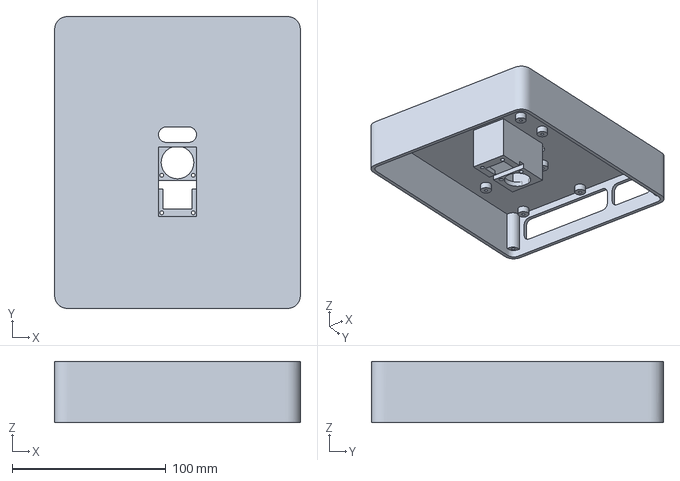
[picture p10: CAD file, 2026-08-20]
hardware/reference_lelamp/original_3mf/LampBase.3mf
160.0 x 190.0 x 40.0 mm

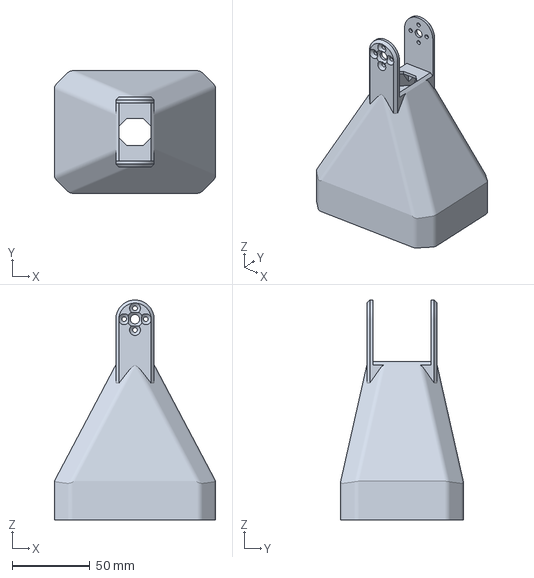
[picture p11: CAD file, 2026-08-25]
hardware/reference_lelamp/print_ready_mm/LampHead - LampHead.3mf
104.0 x 79.0 x 141.7 mm

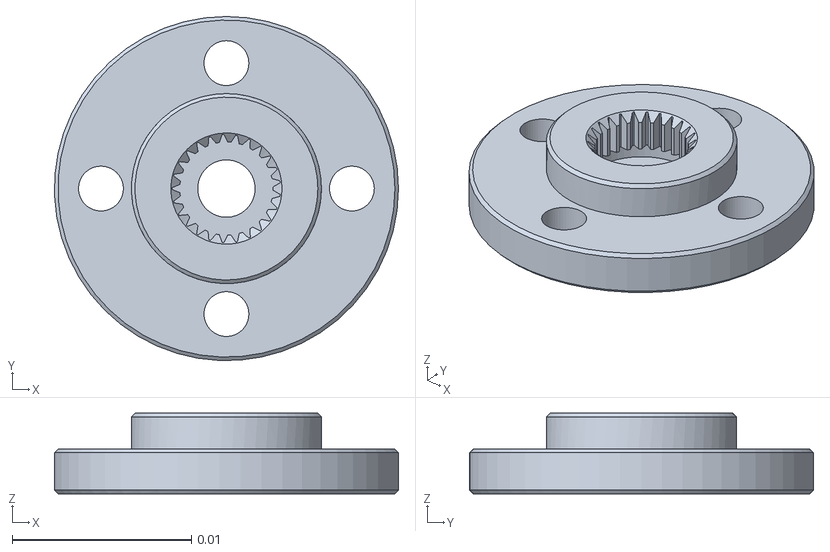
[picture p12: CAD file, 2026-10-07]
simulation/mujoco/v2/meshes/common_REF_Fixed_neck_swivel_horn_-_supplier_geometry.stl
0.0192 x 0.0192 x 0.0045

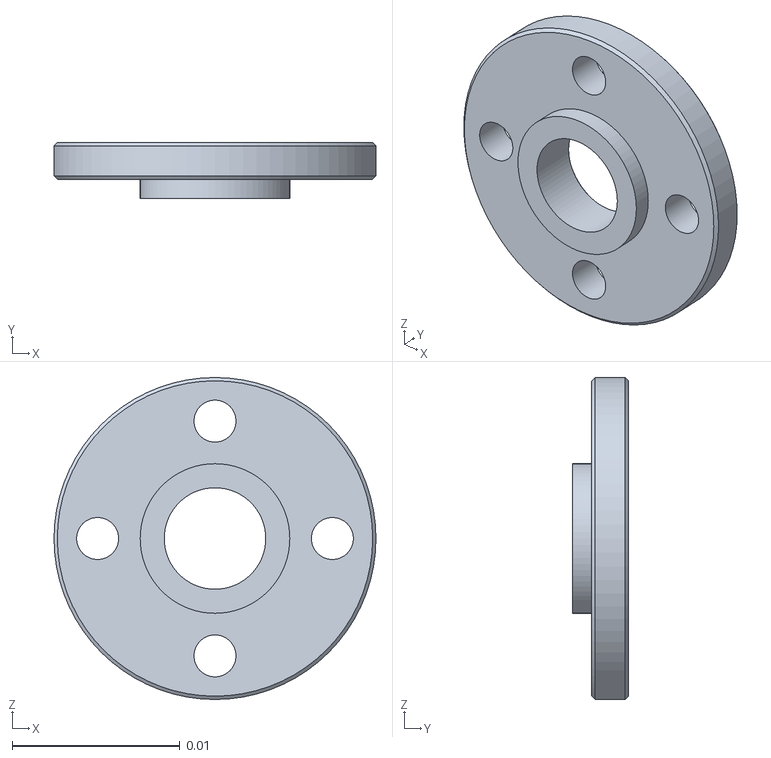
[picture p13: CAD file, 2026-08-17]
description/meshes/servo_horn_driven.stl
0.0192 x 0.00335 x 0.0192

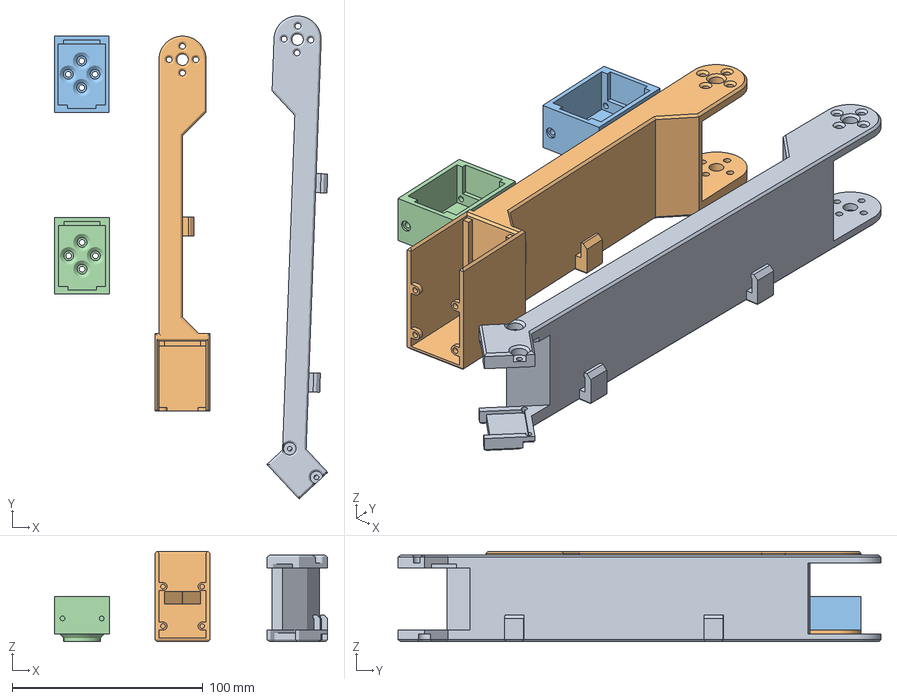
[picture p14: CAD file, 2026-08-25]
hardware/reference_lelamp/print_ready_mm/LampArm (Base-Elbow) - LampArm (Base-Elbow).3mf
143.2 x 252.9 x 47.2 mm
LampArm (Base-Elbow) - LampArm (Base-Elbow).stl
LampArm (Elbow-Wrist) - LampArm (Elbow-Wrist).stl
LampArm (Wrist-Head) - LampArm (Wrist-Head).stl x 2

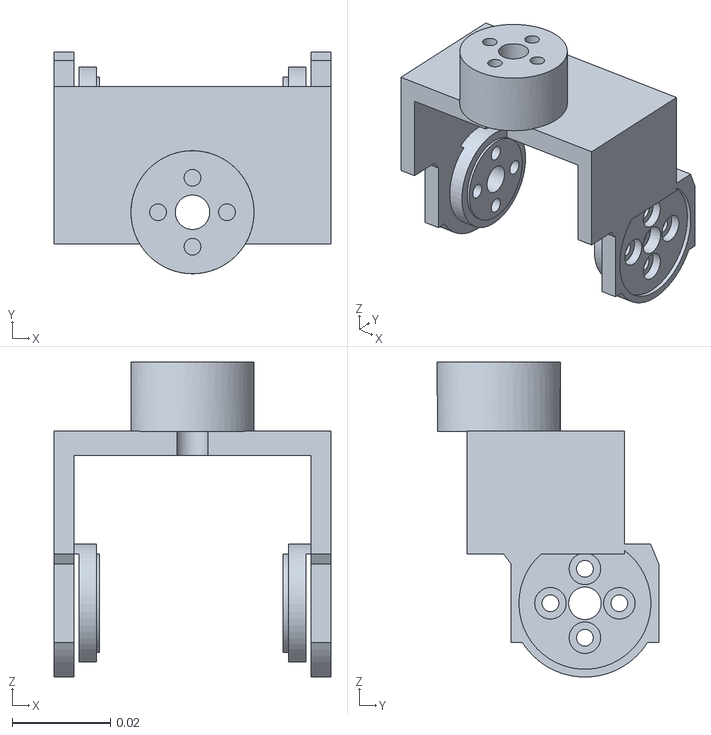
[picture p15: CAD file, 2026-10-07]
simulation/mujoco/v2/meshes/v21_16_Pitch_fork_and_fixed_swivel_post.stl
0.0562 x 0.045 x 0.064

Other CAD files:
hardware/reference_lelamp/original_3mf/LampHead - Diffuser.3mf
hardware/reference_lelamp/original_3mf/LampBase - Cover.3mf
description/meshes/lamphead.stl
hardware/reference_lelamp/original_3mf/LampArm (Base-Elbow).3mf
description/meshes/lamp_base.stl
description/meshes/lamp_base_cover.stl
description/meshes/lamparm__base_elbow.stl
description/meshes/lamparm__elbow_wrist.stl
description/meshes/lamparm__wrist_head.stl
description/meshes/motor_1723_3.stl
description/meshes/servo_horn_driving.stl
description/meshes/sg_ziji_15.stl
description/meshes/xg_ziji_16.stl
description/meshes/zk_122.stl
hardware/reference_lelamp/original_3mf/LampArm (Pitch).3mf
hardware/reference_lelamp/original_3mf/LampHead.3mf
hardware/reference_lelamp/print_ready_mm/LampArm (Base-Elbow) - LampArm (Base-Elbow).stl
hardware/reference_lelamp/print_ready_mm/LampArm (Elbow-Wrist) - LampArm (Elbow-Wrist).stl
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

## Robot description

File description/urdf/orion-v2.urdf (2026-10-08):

<?xml version='1.0' encoding='utf-8'?>
<robot name="orion_v2">
  <link name="v21_base">
    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
    <inertial>
      <origin xyz="0.0005275892632188866 0.002492804132918842 0.029951699678330147" rpy="0 0 0" />
      <mass value="0.6947885981257919" />
      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
    </inertial>
  </link>
  <link name="v21_base_yaw_link">
    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
    <inertial>
      <origin xyz="-0.00027937867087692334 -9.814873935977057e-05 0.03581569279787336" rpy="0 0 0" />
      <mass value="0.1371237843561927" />
      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
    </inertial>
  </link>
  <joint name="base_yaw_joint" type="revolute">
    <parent link="v21_base" />
    <child link="v21_base_yaw_link" />
    <origin xyz="0.0 0.0 0.060000000000000005" rpy="0 0 0" />
    <axis xyz="0 0 -1" />
    <limit lower="-1.5707963267948966" upper="1.5707963267948966" effort="0" velocity="0" />
  </joint>
  <link name="v21_shoulder_pitch_link">
    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
    <inertial>
      <origin xyz="0.0001027393582969521 1.775105797327372e-07 0.0943820574613771" rpy="0 0 0" />
      <mass value="0.22047429579639194" />
      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
    </inertial>
  </link>
  <joint name="shoulder_pitch_joint" type="revolute">
    <parent link="v21_base_yaw_link" />
    <child link="v21_shoulder_pitch_link" />
    <origin xyz="0.0 0.0 0.05299999999999999" rpy="0 0 0" />
    <axis xyz="1 0 0" />
    <limit lower="-1.5707963267948966" upper="1.5707963267948966" effort="0" velocity="0" />
  </joint>
  <link name="v21_elbow_pitch_link">
    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
    <inertial>
      <origin xyz="5.498822803899592e-05 3.9842554842618e-07 0.08752514705954868" rpy="0 0 0" />
      <mass value="0.17659699753478608" />
      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
    </inertial>
  </link>
  <joint name="elbow_pitch_joint" type="revolute">
    <parent link="v21_shoulder_pitch_link" />
    <child link="v21_elbow_pitch_link" />
    <origin xyz="0.0 0.0 0.15000000000000002" rpy="0 0 0" />
    <axis xyz="1 0 0" />
    <limit lower="-2.705260340591211" upper="2.705260340591211" effort="0" velocity="0" />
  </joint>
  <link name="v21_wrist_pitch_link">
    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
    <inertial>
      <origin xyz="-4.7410191747457615e-05 -0.007809009277039256 0.02361771036186182" rpy="0 0 0" />
      <mass value="0.05054645843235149" />
      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
    </inertial>
  </link>
  <joint name="head_pitch_joint" type="revolute">
    <parent link="v21_elbow_pitch_link" />
    <child link="v21_wrist_pitch_link" />
    <origin xyz="0.0 0.0 0.131" rpy="0 0 0" />
    <axis xyz="1 0 0" />
    <limit lower="-1.5707963267948966" upper="1.5707963267948966" effort="0" velocity="0" />
  </joint>
  <link name="v21_neck_swivel_link">
    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
    <inertial>
      <origin xyz="-4.377315539681308e-05 -0.03902162685249138 0.02085453717818393" rpy="0 0 0" />
      <mass value="0.29925124595845126" />
      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
    </inertial>
  </link>
  <joint name="head_roll_joint" type="revolute">
    <parent link="v21_wrist_pitch_link" />
    <child link="v21_neck_swivel_link" />
    <origin xyz="0.0 -0.0175 0.04899999999999999" rpy="0 0 0" />
    <axis xyz="0 0 -1" />
    <limit lower="-1.5707963267948966" upper="1.5707963267948966" effort="0" velocity="0" />
  </joint>
</robot>

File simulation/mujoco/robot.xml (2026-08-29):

<?xml version="1.0" ?>
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
<mujoco model="simulation">
  <compiler angle="radian" meshdir="../../description/meshes" autolimits="true"/>
  <default>
    <default class="simulation">
      <joint frictionloss="0.1" armature="0.005"/>
      <position kp="50" dampratio="1"/>
      <default class="visual">
        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
      </default>
      <default class="collision">
        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
      </default>
    </default>
  </default>
  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
  <sensor>
    <accelerometer name="accel_sensor" site="imu_site"/>
    <gyro name="gyro_sensor" site="imu_site"/>
  </sensor>
  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
  <default>
    <default class="sts3215">
      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
      <joint damping="0.60" frictionloss="0.052" armature="0.028"/>
      <position kp="17.8" kv="0.0" forcerange="-3.35 3.35"/>
    </default>
    <default class="backlash">
      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
      <joint damping="0.01" frictionloss="0" armature="0.01" limited="true" range="-0.008726646259971648 0.008726646259971648"/>
    </default>
  </default>
  <worldbody>
    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
    <body name="lamparm__base_elbow" pos="0 0 0" quat="1 0 0 0" childclass="simulation">
      <freejoint name="lamparm__base_elbow_freejoint"/>
      <inertial pos="0.0729066 -0.0229022 0.217607" mass="0.234138" fullinertia="0.0010919 0.00129476 0.000320305 7.35843e-05 -0.000504692 0.000161616"/>
      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
      <body name="lamparm__wrist_head" pos="0.00583234 0.0182927 0.08291" quat="0.570913 -0.417203 0.570913 0.417203">
        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
        <joint axis="0 0 1" name="shoulder_pitch_joint" type="hinge" ref="0.096485421696463" range="-1.431204075097303 0.805339913639962" class="sts3215"/>
        <inertial pos="0.0193636 0.000541554 -0.0196637" mass="0.0953804" fullinertia="1.16713e-05 2.19256e-05 1.7794e-05 -3.19269e-07 9.361e-07 6.98105e-08"/>
        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
        <body name="scs215_v5" pos="0.04111 7.30741e-16 -0.0192" quat="0.5 -0.5 -0.5 0.5">
          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
          <joint axis="0 0 1" name="base_yaw_joint" type="hinge" ref="0.315320384242287" range="-1.540116711037184 1.540116711037184" class="sts3215"/>
          <inertial pos="0.00584437 0.00206639 -0.0244202" mass="0.41735" fullinertia="0.00100304 0.00122902 0.00205034 -8.49257e-05 -8.64397e-06 -3.34823e-06"/>
          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
        </body>
      </body>
      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
      <body name="lamparm__elbow_wrist" pos="0.105806 -0.0129789 0.301237" quat="0.575614 0.423658 -0.566139 0.410693">
        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
        <joint axis="0 0 1" name="elbow_pitch_joint" type="hinge" ref="0.331339850183298" range="-1.013961300792409 1.036971012100692" class="sts3215"/>
        <inertial pos="-0.00212937 0.119295 0.0220282" mass="0.206448" fullinertia="0.000632713 4.80236e-05 0.000602863 -1.84707e-05 -1.72868e-06 -1.49987e-05"/>
        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
        <body name="lamparm__wrist_head_2" pos="2.55351e-15 0.185185 0.006125" quat="0.670659 0.670659 -0.224092 0.224092">
          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
          <joint axis="0 0 1" name="head_roll_joint" type="hinge" ref="0.712126211333258" range="-1.540116711037184 1.474155537158101" class="sts3215"/>
          <inertial pos="0.000541554 -0.000463734 -0.0217464" mass="0.0953804" fullinertia="2.19256e-05 1.7794e-05 1.16713e-05 6.98105e-08 -3.19269e-07 9.361e-07"/>
          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
          <body name="diffuser" pos="1.58207e-15 0.0192 -0.04111" quat="0.5 0.5 -0.5 0.5">
            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
            <joint axis="0 0 1" name="head_pitch_joint" type="hinge" ref="0.053689327575997" range="-0.533825314184203 0.705631162427395" class="sts3215"/>
            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
            <inertial pos="-0.0641891 0.0560099 0.0186249" mass="0.120" fullinertia="0.000211444487431 0.000218702772333 0.000265137019846 2.65412227672e-05 9.28237416047e-11 5.15798622461e-10"/>
            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
          </body>
        </body>
      </body>
    </body>
  </worldbody>
  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
  <actuator>
    <position class="sts3215" name="base_yaw_joint" joint="base_yaw_joint" inheritrange="1"/>
    <position class="sts3215" name="shoulder_pitch_joint" joint="shoulder_pitch_joint" inheritrange="1"/>
    <position class="sts3215" name="elbow_pitch_joint" joint="elbow_pitch_joint" inheritrange="1"/>
    <position class="sts3215" name="head_roll_joint" joint="head_roll_joint" inheritrange="1"/>
    <position class="sts3215" name="head_pitch_joint" joint="head_pitch_joint" inheritrange="1"/>
  </actuator>
  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
  <equality/>
</mujoco>

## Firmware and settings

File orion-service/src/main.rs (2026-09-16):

use orion_service::{Host, Request, rpc};
use std::{path::PathBuf, sync::Arc};

fn main() {
    let runtime = tokio::runtime::Builder::new_multi_thread()
        .worker_threads(2)
        .enable_all()
        .build()
        .expect("Orion service runtime");
    let result = runtime.block_on(run());
    runtime.shutdown_timeout(std::time::Duration::from_secs(2));
    if let Err(error) = result {
        eprintln!("orion-service: {error}");
        std::process::exit(1);
    }
}
async fn run() -> Result<(), String> {
    let arguments: Vec<_> = std::env::args().skip(1).collect();
    let command = arguments.first().map(String::as_str).unwrap_or("serve");
    if matches!(command, "--help" | "help") {
        println!(
            "Usage: orion-service [serve [--no-autostart] | status | check]\nPi installation: python3 scripts/install_pi_voice_stack.py"
        );
        return Ok(());
    }
    if arguments.len() > 2
        || (arguments.len() == 2 && !(command == "serve" && arguments[1] == "--no-autostart"))
    {
        return Err("Unexpected arguments; use --help".into());
    }
    let directory = rpc::service_home()?;
    if command == "status" {
        println!("{}", rpc::call(&directory, &Request::Status)?);
        return Ok(());
    }
    if command == "check" {
        let root = orion_service::project_root()?;
        let python = std::env::var_os("ORION_STUDIO_VOICE_PYTHON")
            .map(PathBuf::from)
            .unwrap_or_else(|| root.join("speech/.venv/bin/python"));
        if !python.is_file() || !root.join("speech/orion_speech_worker/worker.py").is_file() {
            return Err(
                "Prepare the speech worker and its Python environment before starting".into(),
            );
        }
        orion_service::settings::load_voice_settings()?.validate()?;
        println!("Orion service files and settings are ready");
        return Ok(());
    }
    if command != "serve" {
        return Err("Unknown command; use --help".into());
    }
    let host = Arc::new(Host::new(&directory)?);
    let listener = tokio::net::TcpListener::bind("127.0.0.1:0")
        .await
        .map_err(|e| e.to_string())?;
    let token = uuid::Uuid::new_v4().simple().to_string();
    let publication = rpc::Publication::new(
        &directory,
        &rpc::Connection {
            protocol: rpc::PROTOCOL,
            address: listener.local_addr().map_err(|e| e.to_string())?,
            token: token.clone(),
        },
    )?;
    let autostart = !arguments.iter().any(|arg| arg == "--no-autostart");
    let mut tasks = tokio::task::JoinSet::new();
    let mut maintenance: Option<tokio::task::JoinHandle<()>> = None;
    let mut interval = tokio::time::interval(std::time::Duration::from_secs(5));
    #[cfg(unix)]
    let mut terminate = tokio::signal::unix::signal(tokio::signal::unix::SignalKind::terminate())
        .map_err(|e| e.to_string())?;
    let stop = async {
        #[cfg(unix)]
        tokio::select! { _ = terminate.recv() => {}, _ = tokio::signal::ctrl_c() => {} }
        #[cfg(not(unix))]
        let _ = tokio::signal::ctrl_c().await;
    };
    tokio::pin!(stop);
    eprintln!("orion-service: control service ready");
    loop {
        tokio::select! {
            _ = &mut stop => break,
            _ = interval.tick(), if autostart => {
                if maintenance.as_ref().is_none_or(|task| task.is_finished()) {
                    let host = host.clone();
                    maintenance = Some(tokio::spawn(async move { host.maintain().await; }));
                }
            },
            Some(_) = tasks.join_next() => {},
            accepted = listener.accept() => {
                let (stream, _) = accepted.map_err(|e| e.to_string())?;
                if tasks.len() < 16 {
                    let token = token.clone(); let host = host.clone();
                    tasks.spawn(async move { rpc::serve(stream, &token, host).await; });
                }
            }
        }
    }
    drop(publication);
    if let Some(task) = maintenance {
        task.abort();
        let _ = task.await;
    }
    tasks.abort_all();
    while tasks.join_next().await.is_some() {}
    host.shutdown();
    eprintln!("orion-service: stopped");
    Ok(())
}

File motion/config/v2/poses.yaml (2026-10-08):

format_version: 2
units: radians
poses:
  home:
    description: V2 powered home measured on 2026-10-08 relative to the captured physical
      calibration zero.
    tags:
    - powered
    - idle_anchor
    - home
    default_lighting: warm_idle_breathe
    positions:
      base_yaw_joint: 0.06
      shoulder_pitch_joint: 0.308
      elbow_pitch_joint: -0.256
      head_roll_joint: -0.021
      head_pitch_joint: -0.14
    idle_profile: home
  attentive:
    description: 'V1 attentive intent on V2: arm and head-pitch offsets from V1 home, neck
      swivel leading the base turn at half its angle; hardware playback unverified.'
    tags:
    - simulation_preview
    default_lighting: warm_idle_breathe
    positions:
      base_yaw_joint: -0.24
      shoulder_pitch_joint: 0.208
      elbow_pitch_joint: -0.231
      head_roll_joint: -0.171
      head_pitch_joint: -0.06
    idle_profile: attentive
  thinking:
    description: 'V1 thinking intent on V2: arm and head-pitch offsets from V1 home, neck
      swivel leading the base turn at half its angle; hardware playback unverified.'
    tags:
    - simulation_preview
    default_lighting: warm_idle_breathe
    positions:
      base_yaw_joint: -0.1
      shoulder_pitch_joint: 0.128
      elbow_pitch_joint: -0.151
      head_roll_joint: -0.101
      head_pitch_joint: -0.12
  curious:
    description: 'V1 curious intent on V2: arm and head-pitch offsets from V1 home, neck swivel
      leading the base turn at half its angle; hardware playback unverified.'
    tags:
    - simulation_preview
    default_lighting: warm_idle_breathe
    positions:
      base_yaw_joint: 0.24
      shoulder_pitch_joint: 0.268
      elbow_pitch_joint: -0.311
      head_roll_joint: 0.069
      head_pitch_joint: 0.02
  delight:
    description: 'V1 delight intent on V2: arm and head-pitch offsets from V1 home, neck swivel
      leading the base turn at half its angle; hardware playback unverified.'
    tags:
    - simulation_preview
    default_lighting: warm_idle_breathe
    positions:
      base_yaw_joint: 0.06
      shoulder_pitch_joint: 0.468
      elbow_pitch_joint: -0.391
      head_roll_joint: -0.021
      head_pitch_joint: 0.120001
  rest:
    description: Captured torque-free mechanical rest on 2026-10-07.
    tags:
    - shutdown_only
    - mechanical_rest
    default_lighting: 'off'
    positions:
      base_yaw_joint: 0.04908738521234052
      shoulder_pitch_joint: -0.5553010452146021
      elbow_pitch_joint: 0.8820389530342436
      head_roll_joint: -0.01380582709097077
      head_pitch_joint: 0.2193592526676467
  zero_reference:
    description: V2.1 CAD all-zero reference, not a captured physical zero.
    tags:
    - simulation_preview
    - calibration_reference
    positions:
      base_yaw_joint: 0.012447
      shoulder_pitch_joint: 0.237437
      elbow_pitch_joint: -0.223786
      head_roll_joint: -0.007194
      head_pitch_joint: -0.259651
  look_left:
    description: 'V1 look_left intent on V2: arm and head-pitch offsets from V1 home, neck
      swivel leading the base turn at half its angle; hardware playback unverified.'
    tags:
    - simulation_preview
    default_lighting: warm_idle_breathe
    positions:
      base_yaw_joint: -1.168
      shoulder_pitch_joint: 0.208
      elbow_pitch_joint: -0.231
      head_roll_joint: -0.635
      head_pitch_joint: -0.06
    idle_profile: directional
  look_left_anticipation:
    description: 'V1 look_left_anticipation intent on V2: arm and head-pitch offsets from
      V1 home, neck swivel leading the base turn at half its angle; hardware playback unverified.'
    tags:
    - simulation_preview
    default_lighting: warm_idle_breathe
    positions:
      base_yaw_joint: 0.14
      shoulder_pitch_joint: 0.268
      elbow_pitch_joint: -0.231
      head_roll_joint: 0.019
      head_pitch_joint: -0.04
  look_left_lean:
    description: 'V1 look_left_lean intent on V2: arm and head-pitch offsets from V1 home,
      neck swivel leading the base turn at half its angle; hardware playback unverified.'
    tags:
    - simulation_preview
    default_lighting: warm_idle_breathe
    positions:
      base_yaw_joint: -0.818
      shoulder_pitch_joint: 0.128
      elbow_pitch_joint: -0.151
      head_roll_joint: -0.46
      head_pitch_joint: -0.1
  look_left_overshoot:
    description: 'V1 look_left_overshoot intent on V2: arm and head-pitch offsets from V1
      home, neck swivel leading the base turn at half its angle; hardware playback unverified.'
    tags:
    - simulation_preview
    default_lighting: warm_idle_breathe
    positions:
      base_yaw_joint: -1.248
      shoulder_pitch_joint: 0.168
      elbow_pitch_joint: -0.201
      head_roll_joint: -0.675
      head_pitch_joint: -0.07
  attention_left:
    description: 'V1 attention_left intent on V2: arm and head-pitch offsets from V1 home,
      neck swivel leading the base turn at half its angle; hardware playback unverified.'
    tags:
    - simulation_preview
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

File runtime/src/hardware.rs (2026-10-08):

//! Hardware selection preserves the Studio joint-key contract. The profile
//! names the physical mechanism; v2 head_roll is neck swivel, head_pitch wrist.
use crate::{Error, JointCalibration, ORION_JOINT_NAMES, Result, load_calibration_file};
use serde::Deserialize;
use std::{path::Path, str::FromStr, sync::OnceLock};

#[derive(Clone, Copy, Debug, Default, Eq, PartialEq)]
pub enum HardwareVersion {
    #[default]
    V1,
    V2,
}

#[derive(Debug, Deserialize)]
pub struct HardwareProfile {
    pub hardware: String,
    pub mechanical_revision: String,
    pub lighting: LightingProfile,
    pub audio: AudioProfile,
    pub calibration_file: String,
    pub poses: String,
    pub user_poses: String,
    pub motions: String,
    pub scenes: String,
    pub scene: String,
    pub joints: std::collections::BTreeMap<String, JointProfile>,
}
#[derive(Debug, Deserialize)]
pub struct LightingProfile {
    pub layout: String,
    pub pixel_count: usize,
    pub width: usize,
    pub height: usize,
    pub white_temperature_k: u16,
    pub gpio_bcm: u8,
    pub wire_order: String,
    pub frequency_hz: usize,
}
#[derive(Debug, Deserialize)]
pub struct AudioProfile {
    pub backend: String,
    pub card: String,
    pub pcm: String,
    pub capture_channels: usize,
    pub processed_channel: Option<usize>,
}
#[derive(Debug, Deserialize)]
pub struct JointProfile {
    pub servo_id: u8,
    pub physical_joint: String,
}

impl FromStr for HardwareVersion {
    type Err = Error;
    fn from_str(value: &str) -> Result<Self> {
        match value {
            "v1" => Ok(Self::V1),
            "v2" => Ok(Self::V2),
            _ => Err(Error::InvalidArgument(
                "--hardware must be v1 or v2.".into(),
            )),
        }
    }
}
impl HardwareVersion {
    pub fn profile(self) -> &'static HardwareProfile {
        static V1: OnceLock<HardwareProfile> = OnceLock::new();
        static V2: OnceLock<HardwareProfile> = OnceLock::new();
        let (slot, source) = match self {
            Self::V1 => (&V1, include_str!("../../hardware/profiles/v1.json")),
            Self::V2 => (&V2, include_str!("../../hardware/profiles/v2.json")),
        };
        slot.get_or_init(|| {
            serde_json::from_str(source).expect("validated built-in hardware profile")
        })
    }
    pub fn load_calibration(self, path: impl AsRef<Path>) -> Result<Vec<JointCalibration>> {
        let document: serde_json::Value = serde_json::from_slice(&std::fs::read(path.as_ref())?)?;
        let version = document
            .get("hardware")
            .and_then(|v| v.as_str())
            .unwrap_or("v1");
        if version != self.profile().hardware
            || document.get("simulation_only") == Some(&serde_json::Value::Bool(true))
        {
            return Err(Error::Runtime(
                "Calibration hardware does not match --hardware, or is simulation-only.".into(),
            ));
        }
        let calibrations = load_calibration_file(path, &ORION_JOINT_NAMES)?;
        // Each servo ID must drive the mechanism its joint name describes; a
        // calibration taken under another ID map would move the wrong servo.
        for calibration in &calibrations {
            let expected = self.profile().joints[&calibration.name].servo_id;
            if calibration.servo_id != expected {
                return Err(Error::Runtime(format!(
                    "{} uses servo {} in the calibration, but the {} profile maps it to servo {expected}.",
                    calibration.name,
                    calibration.servo_id,
                    self.profile().hardware
                )));
            }
        }
        Ok(calibrations)
    }
}

#[cfg(test)]
mod tests {
    use super::*;
    #[test]
    fn v2_refuses_v1_calibration_before_opening_a_bus() {
        let source = Path::new(env!("CARGO_MANIFEST_DIR"))
            .join("../simulation/mujoco/config/servo_calibration.json");
        assert!(HardwareVersion::V1.load_calibration(&source).is_ok());
        assert!(HardwareVersion::V2.load_calibration(&source).is_err());
        let mut document: serde_json::Value =
            serde_json::from_slice(&std::fs::read(source).unwrap()).unwrap();
        document["hardware"] = serde_json::json!("v2");
        let folder = tempfile::tempdir().unwrap();
        let path = folder.path().join("calibration.json");
        // V1 IDs put the neck joint on servo 4; V2 measured it on servo 5.
        std::fs::write(&path, document.to_string()).unwrap();
        let error = HardwareVersion::V2.load_calibration(&path).unwrap_err();
        assert!(error.to_string().contains("maps it to servo 5"), "{error}");
        document["joints"]["head_roll_joint"]["servo_id"] = serde_json::json!(5);
        document["joints"]["head_pitch_joint"]["servo_id"] = serde_json::json!(4);
        std::fs::write(&path, document.to_string()).unwrap();
        assert!(HardwareVersion::V2.load_calibration(&path).is_ok());
        document["simulation_only"] = serde_json::json!(true);
        std::fs::write(&path, document.to_string()).unwrap();
        assert!(HardwareVersion::V2.load_calibration(&path).is_err());
    }
    #[test]
    fn profiles_preserve_contract_and_name_the_v2_physical_axes() {
        for version in [HardwareVersion::V1, HardwareVersion::V2] {
            let profile = version.profile();
            assert_eq!(
                profile.lighting.pixel_count,
                profile.lighting.width * profile.lighting.height
            );
            assert_eq!(profile.lighting.gpio_bcm, 12);
            assert_eq!(profile.lighting.wire_order, "GRBW");
            assert_eq!(profile.joints.len(), 5);
            for name in ORION_JOINT_NAMES {
                assert!(profile.joints.contains_key(name));
            }
        }
        let v2 = HardwareVersion::V2.profile();
        assert_eq!(v2.joints["head_pitch_joint"].physical_joint, "wrist_pitch");
        assert_eq!(v2.joints["head_roll_joint"].physical_joint, "neck_swivel");
        // Measured on the fitted V2 lamp: servo 4 tilts the head, servo 5 turns it.
        assert_eq!(v2.joints["head_pitch_joint"].servo_id, 4);
        assert_eq!(v2.joints["head_roll_joint"].servo_id, 5);
    }
}

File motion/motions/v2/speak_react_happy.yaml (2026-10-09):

format_version: 2
motion:
  name: speak_react_happy
  description: A bright lift with a small bounce used as a spoken happy reaction.
  space: anchor_relative
  style: attentive
  return_to_anchor: true
  keyframes:
    - offsets: {head_pitch_joint: 0.24, shoulder_pitch_joint: 0.13, elbow_pitch_joint: -0.11}
      duration: 0.28
      arrival: through
      marker: happy
    - offsets: {head_pitch_joint: 0.08, shoulder_pitch_joint: 0.05, elbow_pitch_joint: -0.04}
      duration: 0.20
      arrival: through
    - offsets: {head_pitch_joint: 0.20, shoulder_pitch_joint: 0.10, elbow_pitch_joint: -0.08}
      duration: 0.20
      arrival: through
    - offsets: {}
      duration: 0.35
      arrival: settle

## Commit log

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2026-08-29 fixed calibration servo script
    [calibration.py]
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2026-08-29 CALIBRATION FIXES
    [robot.xml, servo_calibration.json]
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2026-09-02 feat(character): replace motion stack with Orion v2
    [calibration.py, disagree_soft.yaml, idle_attentive_hold.yaml]
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2026-09-02 fix(character): make foreground interruption fail safe
    [main.rs]
2026-09-02 fix(character): preserve anchor through speech
    [main.rs]
2026-09-02 fix(character): clear latched light on shutdown
    [main.rs]
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2026-09-06 refactor(voice): extract Rust coordinator and speech worker from Studio
    Move voice orchestration, Pi transport, playback buffering, and cancellation into a reusable coordinator crate. Keep Python responsible for ASR and TTS through a framed subprocess protocol.
    Host the agent and coordinator independently in Studio so conversation state survives coordinator restarts. Replace Python orchestration tests with coordinator integration tests and speech protocol coverage.
    Update architecture and setup documentation, remove obsolete worker code, and drop unused speech model and Rustpotter directory references.
2026-09-06 updated diffuser stl for a tighter fit in lamp head
    [LampHead - Diffuser.3mf]
2026-09-07 fix(voice): close microphone control WebSockets gracefully
    Send a Close frame after status reads and mute acknowledgements, with a separate bounded cleanup deadline that preserves successful control results.
    Handle abrupt control-client disconnects in the Pi listener without repeated handler tracebacks or interrupted capture. Cover status and mute handshakes, unresponsive close peers and listener recovery with regression tests.
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2026-09-14 Add headless Studio service with launchd startup and release rollback
    Share pairing, settings, agent, and coordinator ownership between desktop and headless launchers. Attach the UI to the background owner and prevent duplicate processing owners.
    Add tested macOS lifecycle and update scripts that prepare complete releases before activation and restore the previous release on startup failure. Document setup, operation, configuration, and Pi deployment.
    [main.rs]
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2026-09-27 feat: improve voice reliability, wake verification, and motion diagnostics
    Preserve complete spoken answers, recover clean agent turns, improve timezone
    and tool error handling, and expose manual lighting state.
    Sustain long speech with complete-reply buffering for slow synthesis,
    incremental audio analysis, a clear 30-minute sanity cap, playback progress
    checks, and silent session lease renewals.
    Add acoustic wake verification and packaged verifier models, update listener
    and Pi deployment defaults, and cover verification ordering with tests.
    Refine speech and idle animation, add servo tracking and controlled gain
    experiments with analysis and safety checks, and update architecture and
    o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
    [idle_attentive_hold.yaml, idle_breathe.yaml, idle_directional_hold.yaml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]
2026-09-27 fix(deploy): exclude native MuJoCo tests from Pi releases
    Use the shared native_mujoco test filter so character-animation simulation tests are excluded alongside the driver simulation test. Pi releases prepare voice and speech environments without the workstation root simulation environment.
    Add regression coverage for both exclusions while preserving the other runtime checks, and document the Pi test boundary.
2026-09-27 fix(deploy): update built-in YAML and restore physical smoke tests
    Update managed pose, motion and scene YAML within the release rollback transaction while preserving user assets and Pi calibration. Validate the planned motion catalog before switching services.
    Measure rest before switching, run the light/audio and expressive motion smoke sequence with companions stopped, and finish in voice-wakeable rest with lights and torque off. Cover asset ownership, rollback, smoke ordering and measured rest failures with regression tests.
2026-09-27 fix(deploy): read rest lifecycle from character status
    The core status response contains movement and torque but no rest lifecycle. Query character status separately in smoke settling and readiness so the completion checks can succeed.
    Use separate response fixtures, cover asynchronous completion and failure diagnostics, avoid retrying failed initial rest, and report each smoke stage.
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2026-10-08 head fix for v2
    [calibration.py, hardware.rs, poses.yaml]
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2026-10-08 Add opt-in live wake verifier diagnostics
    ORION_WAKE_DEBUG_DIR enables a four-second ring of exact verifier PCM and all scorer chunk results. At each verdict a bounded daemon writer saves WAV and metadata, retaining fifty diagnostic folders. Alarm dismissal creates no snapshots; slow or failed writes do not alter wake decisions.
    Metadata includes candidate phase and sample positions, verdict, score eligibility, verifier health, recent chunk processing times and capture-open age. Capture read latency logs summarize reads exceeding 40 ms once a minute. Wake thresholds, models and state transitions are unchanged.
    Validation: full voice unittest discovery, 114 tests with one optional ONNX skip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
2026-10-09 Make speech reactions readable in short replies
    [speak_react_agree.yaml, speak_react_disagree.yaml]
2026-10-10 camera P0: add headless camera setup and in-memory benchmarks
    Add Ubuntu 24.04 / Pi 5 commissioning tools:
    - Build libpisp, Raspberry Pi libcamera with rpi/pisp and Python bindings,
    and headless rpicam-apps under /usr/local. Verify pinned tags against
    commit IDs, purge only installed camera packages, expose the Python
    binding path and grant video-group DMA access. Re-runs replace the same
    configuration and rebuild the same releases.
    - Verify imx708_wide discovery, Python bindings and the three Pi 5 drivers.
    - Measure main/lores delivery, YuNet and YOLO11n NCNN-320 at one/two threads,
    inference latency, temperature and capture timestamp provenance. Consume
    only the latest in-memor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
2026-10-10 camera P0: review fixes
    Fix the installer PATH so Ubuntu administrative tools remain available,
    and pair rpicam-apps 1.7.0 with Raspberry Pi libcamera 0.5.0+rpt20250429.
    Document the pinned KMS Python binding required by Picamera2 on Ubuntu,
    NCNN's desktop-to-headless OpenCV replacement, and preserving working
    camera auto-detection. Crop ISP padding after YUV conversion for both
    inference models; add PATH and padded-input regressions.
    Checks:
    - python3 -m unittest discover -s scripts/tests -v: 125 passed,
    including 16 camera tests.
    - bash -n vision/scripts/install-camera-stack.sh: passed.
    - bash -n vision/scripts/verify-camera-stack.sh: passed.
    - python3 -m py_compile vision/scripts/measu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
2026-10-10 camera P0: review fixes
    Remove lamp acceptance status from the component README; measured hardware
    outcomes remain in the prior P0 commit messages. Delete the authorized
    orientation snapshot from the ignored local gate directory and the Pi's
    temporary gate directory, and remove its link from ignored commissioning
    notes. Only vision/README.md is included in this commit.
    - git diff --check: passed.
    - Local and Pi snapshot absence checks: passed.
    - Reviewed the README diff and staged file list: README only.
    - Runtime tests not repeated for this documentation-only change.
    Unverified on hardware: existing sensor-to-joint timestamp alignment,
    long thermal soak, service-quota detector bud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
2026-10-10 camera P1: add URDF-derived camera and light kinematics
    Add nominal fixed camera_optical_frame and light_frame mounts to the V2
    URDF and matching MuJoCo camera/site definitions. Preserve existing model
    links, joint origins, axes, ranges and meshes. Document ROS optical axes
    (+X right, +Y down, +Z forward) and MuJoCo's camera-axis conversion.
    Add Kinematics::from_urdf and fallible fk(&JointPositions), returning camera
    and light poses in the base frame. Read origins and axes from a validated
    connected URDF tree; load once outside the control tick. FK rejects wrong
    joint names and non-finite angles, does no I/O or allocation on valid input,
    and does not treat CAD limits as servo calibration. A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
2026-10-10 camera P2: add bounded camera service and profile-gated deployment
    Add Picamera2, replay and MuJoCo-stub sources, exposure-midpoint BOOTTIME
    validation, one latest RGB frame and shared on-demand 640x360 JPEG encoding
    at at most 15 fps over a private Unix HTTP socket. Watch the saved camera
    privacy preference, close capture and purge buffers when disabled.
    Pin vision dependencies with uv; expose source-built Pi bindings through a
    system-Python environment. Build pinned kms++ in the native installer. Add
    the V2 camera profile and resource-limited service, profile-gated release
    preparation/activation, privacy-off readiness and transactional rollback.
    Document capture, privacy, clocks and insta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
2026-10-10 camera P3: add authenticated Studio feed and expiring viewer indicator
    Proxy camera stream, snapshot and observations through the existing bearer
    authentication. Persist strict camera privacy settings atomically, pass
    camera_off errors through, bound viewers and end feeds if indicator renewal
    fails. Studio reads incremental multipart JPEGs with authenticated fetch,
    reconnects after network drops, paints the latest frame on a canvas, and
    provides capture controls, explicit snapshot downloads and Debug overlays.
    Add the approved runtime scope for camera-viewer 3/0: a three-second lease
    renewed by the gateway. Keep the faint cyan ring pixel out of the saved light
    frame, below scenes/speech/rin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
2026-10-10 camera P2/P3: review fixes
    Address review items 1-3 without changing the reviewed package commits.
    Refuse authenticated streams and snapshots with 503 camera_resting during
    going_to_rest, resting, waking and fault. Fail closed if rest telemetry cannot
    be verified. Poll rest once per 100 ms across all viewers and stop forwarding
    open streams when rest begins, preserving the runtime's rest lighting mask.
    Make snapshots share the stream viewer-marker lease. Renew camera-viewer 3
    after delivery and retain the indication for three seconds; stream cleanup
    cannot clear a snapshot hold early. A failed snapshot extension leaves the
    existing lease to expire instead of explicitly clearing it immediat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
2026-10-11 camera P3: review fixes
    Fix Studio's disabled connection controls while a saved lamp is loading or
    connecting. Form submissions have their own busy state, so background attempts
    leave Get code, token pairing, address changes and saved-lamp switching usable.
    Provide an active cancel action and keep saved-lamp controls visible beside
    the pairing form.
    Guard saved-lamp refresh results and subsequent startup transitions by the
    connection generation. A cancelled startup that finishes listing lamps must
    not return Studio to Connecting with no active request. Cancel spoken-code
    requests through AbortController, retain their existing timeout, and ignore
    late cancelled results without disconnecting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
2026-10-11 camera P3: review fixes
    Show the pending pairing operation instead of labelling every wait Connecting:
    code exchange, Orion verification, credential reads and credential saving.
    Credential waits point to the system permission dialog. Clear the step after
    cancellation, errors or connection, and finish listing saved lamps before
    publishing the connected state. Document the macOS Keychain recovery action.
    - Regression tests before implementation: 6 failed, 43 passed.
    - Studio test suite: 48 files, 283 tests passed.
    - Final pairing controller/panel tests: 49 passed, including a pending saved-
    lamp listing before connected is published.
    - Studio TypeScript/Vite build: passed; existing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
2026-10-11 camera P3: review fixes
    Make the authenticated camera feed work in macOS Studio. WebKit cancels
    multipart/x-mixed-replace fetch loads when the resource is not an image.
    The gateway now advertises multipart/mixed while forwarding JPEG parts,
    boundaries and timestamps unchanged. Studio accepts both content types.
    Authentication, rest gating, privacy checks and viewer leases are unchanged.
    Keep stream failures visible throughout retries, clearing them on a live frame.
    Document the matching Pi gateway update required for Mac viewing.
    - Regression tests failed before the fixes: MIME parser/transport tests,
    gateway stream MIME test and retry-error visibility test.
    - pnpm --dir orion_stu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
2026-10-11 camera P3: review fixes
    Replace the faint single-pixel viewer marker with a bright cyan pulse across
    the V2 ring. Green and blue vary smoothly from 128 to 255 over two seconds;
    red and white remain off. Apply the indicator at the lighting device boundary
    so manual lighting, scenes, speech and ringing cannot cover it. Retain the
    latest underlying frame and restore it when the viewer lease clears or expires.
    Gate the indicator on awake/disabled rest states before lighting writes and
    again after the rest tick. Going to rest, resting, waking and faults suppress
    it even when sunrise bypasses the ordinary darkness mask. Preserve the existing
    three-second lease, V1 rejection, lighting preferences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
2026-10-11 camera P3: viewer indicator band
    Replace the full-ring pulse with three steady full-brightness cyan pixels:
    RGBW(0,255,255,0). V2_CAMERA_VIEWER_START_PIXEL is 15, selecting indices
    15,16,17 at the top centre of the ring as viewed from the front, with index
    16 in the middle. The remaining 21 pixels keep the underlying frame exactly.
    Keep the band at the lighting-device boundary above manual, scene, speech
    and alarm writes, outside the saved base frame. Preserve the existing rest,
    waking, fault and sunrise gates, three-second lease and explicit clearing.
    Update the runtime and Studio indicator documentation. Cover white, off and
    varying frames at multiple times, exact clearing and lease-expir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
2026-10-11 camera P4: V2 URDF zero matches the robot
    Bake the exact measured pitch references into V2 URDF origins and MJCF refs.
    Use safe calibrated ranges in both models and record the calibration hash
    and applied model paths. Remove only V2 Studio preview offsets; keep V1.
    Regenerate camera/light FK fixtures and document the bent calibrated zero.
    Prove old FK(q - ref) equals new FK(q) to 1e-12 at home, rest and random
    poses; verify the measured home link/view angles and every V2 pose limit.
    Update sign tests for the baked geometry while retaining direction checks.
    No servo calibration, existing pose/motion/scene or mesh changes.
    Checks (all pass):
    - cargo fmt --manifest-path runtime/Cargo.toml --c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
2026-10-11 camera P4: query capture-time camera rays from measured pose history
    Load V2 URDF kinematics once from the daemon catalog working directory.
    Missing or invalid geometry disables only camera-rays with a clear cause.
    Record measured feedback in a fixed-capacity, one-second pose ring after
    successful tick reads, timestamped with Linux CLOCK_BOOTTIME. Inject clocks
    in tests; macOS simulation uses its suspend-aware continuous boot clock.
    Add strict camera-rays JSON queries for 1-16 finite unit rays, interpolating
    capture-time poses and returning base azimuth/elevation and pose age. Reject
    stale captures, future times over 50 ms, and stale feedback. Querying never
    moves the robot or changes mode,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
2026-10-11 camera P5: compile neck-first bearing gaze with bounded anchor returns
    Add opt-in V2 GazeCoordinator, strict target/clear/status commands, FK-based
    neck/pitch aiming and slow base catch-up. All movement uses the existing
    anchor-relative trajectory compiler, calibration and zero-offset settle.
    Bound updates to 10 Hz, reject stale targets, and yield to foreground scenes,
    speech and Stop. Stop forgets gaze metadata before the core cancels movement,
    preserving the existing successful Stop response and preventing restart.
    No earlier package commit was changed. P4 gains read-only model/clock and
    commanded-state accessors for this integration.
    Checks passed:
    - cargo fmt --manifest-path runtime/Ca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
2026-10-11 camera P6: calibrate fisheye faces and track capture-time base bearings
    Add in-memory checkerboard calibration with the OpenCV fisheye model and
    0.5 px RMS acceptance, pinned headless OpenCV and installer-verified YuNet.
    Use the exact 320x240 lores stream, preserving packed ISP padding until YUV
    conversion. One worker replaces pending frames and runs at 10 Hz idle / 3 Hz
    confirmed voice through playback. Camera callbacks only copy and publish.
    Undistort face centres, query P4 camera-rays over the runtime Unix socket,
    associate constant-velocity Kalman tracks in base bearings, and send the
    largest frontal face (otherwise largest face) through P5 gaze commands.
    Publish normalized Studio boxes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
2026-10-11 camera P4: review fixes
    Reject interpolation across feedback gaps over 50 ms, preserving exact measured samples and the 50 ms boundary. Add a regression observed failing before the fix; keep normal interpolation fixtures within the valid feedback cadence.
    Checks passed: cargo fmt --check; cargo test --all-targets --locked (287 library + 1 integration); runtime Python unittest discovery (44); root discovery (4); git diff --check. Physical bus-outage recovery and timestamp alignment remain unverified on the lamp.
2026-10-11 camera P5: review fixes
    Latch gaze off after Stop/disable until explicit gaze resume. Name the 1.5 rad/s every-joint compiled peak separately from 0.6 base and 2.5 neck planning-step speeds and report them in status. Report clamping from the bounded achieved bearing; exercise azimuths +/-2.9, +/-1.6 and 3.1 through the validating full loop.
    Regression failures observed before fixes: post-Stop/disable targets accepted, speed status absent, bounded 1.6 rad aim incorrectly unclamped. Compatibility fix in this commit: require the existing P7 post-Stop attention test to reject requests while retaining its no-restart assertion. No earlier commit changed.
    Checks passed: cargo fmt --check; cargo t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
2026-10-11 camera P6: review fixes
    Preserve face tracks when runtime rejects gaze; retry availability at three-second intervals. Retain live targets through misses without replaying capture timestamps and clear once on target loss. Persist and validate ScalerCrop, sensor mode, flips and lores stride; reject legacy calibration, flipped profiles, mismatched negotiated geometry and malformed buffers.
    Correct the fake runtime optical-to-base azimuth sign and test wrapped association, velocity estimation and future prediction. Every reviewed behavior has a regression observed failing before implementation. Synthetic fit/callback fixtures now provide the required geometry; no earlier commit changed.
    Checks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
2026-10-11 camera P7: review fixes
    Select mouth motion using robust adjacent-frame differences above each track noise baseline and require an absolute and relative winner margin; ambiguous evidence uses frontality. Bound visual-attention base travel to 0.65 rad, solve remaining neck/pitch reach and verify the final bearing. Preempt owned background motion before compiling against refreshed feedback.
    Tests observed failing before fixes: 1 px jitter selected a silent face, ambiguous mouths bypassed fallback, 60 degree speakers were refused, and pre-Stop velocity caused a false speed-cap refusal. Test calibrated full-loop turns at +/-60 and +/-100 degrees. Update the obsolete broad-refusal assertion to a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
2026-10-11 camera P7: gaze on by default with resumable stop
    Resolve gaze defaults only for V2 serving on hardware or MuJoCo. Keep V1
    and non-serve operations off, preserve explicit --gaze off, and retain the
    restriction on explicit --gaze on. Camera geometry/clock startup failures
    leave the daemon serving and expose unavailable gaze with its load error.
    Distinguish configured-off, unavailable and stopped gaze from target loss
    and motion handover. Stop/disable keep the latch across clears, idle time,
    reconnecting targets and stale wakes. A successful character start, accepted
    current-session wake confirmation, or scripted gaze resume clears it. Wake
    recovery restores torque/home when needed and rearms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
2026-10-11 camera P7: wake resumes gaze only on a powered lamp
    A confirmed wake after disable must leave torque off and the gaze latch
    closed. Restrict wake recovery to a Stop latch on an already powered,
    enabled character whose startup has completed. Give the recovery helper
    read-only runtime access so it cannot restore torque or start home, and
    rearm rest only when that powered Stop latch was actually cleared.
    Fixes to b88f672 in this commit:
    - Record the latch's stop/disable origin in gaze status. Preserve disable
    across subsequent Stop or clear requests, including after manual enable.
    - Refuse scripted gaze resume while torque is off. Explicit character
    start restores torque/home and clears ei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
2026-10-11 camera P6: replace fitting with built-in wide intrinsics
    Face tracking starts without a camera intrinsics file. Remove the calibration
    CLI, fitting and persistence code, --intrinsics option, fitting/file tests,
    project script entry and obsolete calibration setup instructions.
    Use a nominal OpenCV fisheye model for Camera Module 3 Wide. Derive focal
    length from its 2.75 mm lens and 1.4 um sensor pixels, and derive the first
    distortion coefficient from its 102-degree horizontal field of view.
    Scale intrinsics through the full-view 2304x1296 RAW10 mode, full-sensor
    ScalerCrop and configured 320x240 lores output. Request that geometry
    explicitly, including no additional lores aspect-ratio crop.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
2026-10-11 camera deploy: load release geometry and verify YuNet readiness
    Resolve V2 camera URDF and YuNet from the selected release. Prepare the pinned model with checksum verification before activation, reject unavailable gaze and detector errors, and wait for an inference when capture is enabled.
    Validation: 155 script tests plus the added pin consistency regression, 297 Rust tests, 56 daemon tests, 4 description tests, cargo fmt and doc tests. Regression tests failed before implementation.
2026-10-11 camera Studio: show frame-matched face boxes under viewer leases
    Pair the latest completed inference with its RGB preview and expose normalized boxes, confidence, stable track IDs and chosen-target flags through a viewer-gated detections endpoint. The gateway rechecks lease, rest and privacy before delivery.
    Studio compares exact capture timestamp strings, highlights the chosen target and clears boxes at 300 ms including request delay. Preview data stays bounded in memory, is never logged or persisted, and disappears on viewer release without resetting gaze tracks. Preview rate follows inference (10 Hz idle, 3 Hz voice); detector failure preserves the ordinary camera feed.
    Validation: 44 v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
2026-10-11 Keep camera threads runnable and recover stalled capture
    Raise the vision ceiling to 150% while retaining Nice=10. Reopen capture after a publication gap, retain restart counts across privacy toggles, and bind callbacks to their source generation.
    Validation: vision regression suite and release-install tests pass; sustained lamp capture and ASR comparison remain unverified.
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
